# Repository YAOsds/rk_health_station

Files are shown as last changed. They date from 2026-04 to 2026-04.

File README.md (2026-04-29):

# RK Health Station

本工程是 `esp_health_watch` 的 RK3588 + ESP32 Qt 主站重构版本。

- rk_app/: RK3588 Qt/C++ 主站工程
- esp_fw/: ESP32 固件工程
- protocol/: 对外与本地 IPC 协议文档
- deploy/: systemd 与 bundle 部署脚本
- cmake/toolchains/: RK3588 交叉编译工具链文件

当前项目的主部署方式已经统一为：

- 宿主机 `Ubuntu 22.04` 上交叉编译
- 目标架构 `ARM64 / aarch64`
- 生成可直接传输到 RK3588 的 `rk3588_bundle/`
- 通过 `scp` / `rsync` / `ssh` 将 bundle 传到板端
- 在板端进入 bundle 目录后先编辑 `config/runtime_config.json`，或运行 `./scripts/config.sh`
- 然后使用 `./scripts/start.sh` 或 `./scripts/start_all.sh`

当前仓库默认对接的交叉 SDK 路径为：

- `/home/elf/aarch64-buildroot-linux-gnu_sdk-buildroot`

一键交叉编译并打包：

```bash
bash rk_health_station/deploy/scripts/build_rk3588_bundle.sh
```

只编译 `rk_app`：

```bash
# 当前 Ubuntu 主机本地编译
bash rk_health_station/deploy/scripts/build_rk_app.sh host

# RK3588 交叉编译
bash rk_health_station/deploy/scripts/build_rk_app.sh rk3588
```

默认输出目录：

- `rk_health_station/out/rk3588_bundle`

交叉编译完成后，必须再用 `file` 校验产物架构，例如：

```bash
file rk_health_station/out/rk3588_bundle/bin/healthd
file rk_health_station/out/rk3588_bundle/bin/health-ui
```

期望输出包含 `ARM aarch64`。

详细步骤见：

- `rk_health_station/docs/deployment/rk3588-backend-usage-guide.md`
- `rk_health_station/docs/deployment/rk3588-install.md`
- `rk_health_station/docs/architecture/camera-video-readme.md`

## RK3588 RGA 分析链路环境检查

RK3588 bundle 构建默认启用分析链路的 RGA 转换：

```text
camera/test input NV12 -> health-videod RGA -> RGB 640x640 -> shared memory -> health-falld
```

这个路径只影响跌倒检测所需的分析帧。UI 预览 JPEG 仍走 GStreamer 预览分支，预览编码使用 `mppjpegenc`。

板端运行前可以用下面命令确认环境是否具备 RGA 条件：

```bash
# 1. 确认 RGA 设备节点存在
ls -l /dev/rga

# 2. 确认当前用户具备访问权限；通常需要在 video 组
id

# 3. 确认系统可找到 librga
pkg-config --modversion librga
ldconfig -p | grep -E 'librga\.so'

# 4. 确认 health-videod 产物确实链接到 librga
ldd /home/elf/rk3588_bundle/bin/health-videod | grep rga
```

期望现象：

- `/dev/rga` 存在，且当前用户在 `video` 组或具备等效权限。
- `pkg-config --modversion librga` 能输出版本号。
- `ldd .../health-videod` 能看到 `librga.so`。

启动后可以继续确认当前分析后端：

```bash
cd /home/elf/rk3588_bundle
./scripts/start_all.sh

# 日志中应能看到 analysis_backend=rga
grep 'preview_started' logs/health-videod.log | tail -5

# 当前 GStreamer 分析分支应输出 NV12 到 fdsink，而不是 RGB videoconvert/videoscale
ps -ef | grep '[g]st-launch'
```

RGA 模式下的典型 GStreamer 分析分支形态为：

```text
... videorate drop-only=true ! video/x-raw,format=NV12,width=640,height=480,framerate=15/1 ! fdsink fd=1 sync=false
```

如果看到下面形态，则说明当前使用的是 CPU/GStreamer RGB 转换路径：

```text
... videoconvert ! videoscale ! video/x-raw,format=RGB,width=640,height=640,framerate=15/1 ! fdsink fd=1 sync=false
```

运行时可以用环境变量强制选择分析转换后端：

```bash
# 强制使用 RGA。仅建议在 RK3588 且已确认 /dev/rga 与 librga 可用时设置。
export RK_VIDEO_ANALYSIS_CONVERT_BACKEND=rga

# 强制回退到 GStreamer CPU 转换，便于 A/B 对比或排查 RGA 环境问题。
export RK_VIDEO_ANALYSIS_CONVERT_BACKEND=gstreamer_cpu
```

注意：如果在不具备 RGA 条件的环境中强制设置 `RK_VIDEO_ANALYSIS_CONVERT_BACKEND=rga`，分析分支可能会切到 NV12 输出，但 `health-videod` 无法完成 NV12 到 RGB 的 RGA 转换，导致跌倒检测收不到有效分析帧。遇到这种情况请取消该环境变量，或显式设置为 `gstreamer_cpu` 后重启 bundle。

## DMA / DMABUF 分析链路运行开关

当前仓库已经支持一条板端实测通过的 DMA 分析链路：

```text
GstBuffer / raw frame
-> health-videod 分析支路输入
-> RGA import 输入 fd 或映射后的 bytes
-> RGA 输出 RGB 到 DMA heap fd
-> fd descriptor 发给 health-falld
```

这条路径不是默认打开的，需要在 `config/runtime_config.json` 中显式打开；环境变量只建议作为临时 override。

### 推荐开关组合

在 RK3588 板端推荐直接把下面这些值写进 `config/runtime_config.json`：

```json
{
  "system": {
    "runtime_mode": "system"
  },
  "video": {
    "pipeline_backend": "inproc_gst",
    "analysis_convert_backend": "rga"
  },
  "analysis": {
    "transport": "dmabuf",
    "rga_output_dmabuf": true,
    "gst_dmabuf_input": true,
    "dma_heap": "/dev/dma_heap/system-uncached-dma32"
  },
  "fall_detection": {
    "rknn_input_dmabuf": true
  }
}
```

含义：

- `video.pipeline_backend = inproc_gst`
  - 启用进程内 GStreamer `appsink` 分析分支
  - 不再依赖外部 `gst-launch-1.0 + fdsink`
- `video.analysis_convert_backend = rga`
  - 分析分支使用 RGA 做缩放和颜色转换
- `analysis.transport = dmabuf`
  - `health-videod -> health-falld` 使用 fd descriptor transport
- `analysis.rga_output_dmabuf = true`
  - RGA 直接把 RGB 输出写到 DMA heap fd
- `analysis.gst_dmabuf_input = true`
  - 只启用 `appsink` 输入侧的 DMABUF 探测与日志
  - 如果当前协商出来的 `GstBuffer` 本身就是 `memory:DMABuf`，则优先走输入 fd 路径
  - 这个开关本身不再强制改变摄像头主链格式，也不再默认强制 `v4l2src io-mode=dmabuf`
- `fall_detection.rknn_input_dmabuf = true`
  - `health-falld` 优先走 RKNN 输入侧 DMABUF 路径
- `analysis.dma_heap = /dev/dma_heap/system-uncached-dma32`
  - 当前推荐的 DMA heap
  - 如果不设置，代码也会默认回到这个 heap

### 仍属实验/排查用途的开关

```bash
RK_VIDEO_GST_FORCE_DMABUF_IO=1 ./scripts/start.sh --backend-only
```

含义：

- 强制 `v4l2src io-mode=dmabuf`
- 同时允许 in-process GStreamer 切到实验性的 `UYVY` DMABUF 协商路径
- 当前更适合用作 A/B 对比、排障和板端能力确认
- 只有当板端驱动与插件协商稳定时，才建议写进长期配置

### 默认行为和回退

如果不设置这些开关，默认还是原来的稳定路径：

```text
外部 gst-launch -> raw frame bytes -> RGA/CPU -> shared memory 或 DMABUF descriptor
```

如果只打开一部分开关，行为是分层回退的：

- `video.pipeline_backend` 不是 `inproc_gst`
  - 不会启用进程内 `appsink`
- `analysis.rga_output_dmabuf` 没有打开
  - RGA 输出仍可能回到 `QByteArray` 再发布
- `analysis.gst_dmabuf_input = true` 但板端没有命中 DMABUF
  - 会自动回退到原始 bytes 输入路径
  - 不应丢帧
- `video.pipeline_backend = inproc_gst` 且 `input_mode=test_file`
  - 会自动回退到现有外部 `gst-launch` 文件播放路径
  - 不会再因为 in-process 后端未实现 `filesrc/decodebin` 而导致 `start_test_input` 失败

### 当前板端验证结论

当前这块 RK3588 板子截至 2026-04-29 的最新实测结论是：

- 默认 JSON 配置下，分析链路仍走稳定的 `gstreamer_cpu + shared_memory` 逻辑
- 当下面这组 JSON 配置一起打开时，板端已经实测命中一条完整的 0 拷贝优先路径：

```json
{
  "video": {
    "pipeline_backend": "inproc_gst",
    "analysis_convert_backend": "rga"
  },
  "analysis": {
    "transport": "dmabuf",
    "rga_output_dmabuf": true,
    "gst_dmabuf_input": true,
    "gst_force_dmabuf_io": true
  },
  "fall_detection": {
    "rknn_input_dmabuf": true
  }
}
```

- 对应日志会看到：

```text
video_runtime event=gst_dmabuf_input available payload_bytes=614400 stride=1280 format=UYVY
video_runtime camera=front_cam event=preview_started mode=camera backend=inproc_gst analysis=1 analysis_backend=rga
```

- `health-videod` marker 会看到：

```json
{"transport":"dmabuf","rga_input_dmabuf":true,"rga_output_dmabuf":true}
```

- `health-falld` marker 会看到：

```json
{"input_dmabuf_path":true,"io_mem_path":true,"output_prealloc_path":true}
```

- 也就是说，这块板子的当前高性能路径已经验证为：

```text
GStreamer DMABUF input -> RGA DMABUF output -> RKNN DMABUF input
```

- 这条链路仍依赖板端驱动、插件版本和摄像头协商结果；如果未来更换内核、插件或摄像头格式，仍建议重新做一次板端 smoke

### 板端启动示例

```bash
cd /home/elf/rk3588_bundle

./scripts/config.sh
./scripts/start.sh --backend-only
printf '%s\n' '{"action":"start_preview","request_id":"dmabuf-readme","camera_id":"front_cam","payload":{}}' | \
  nc -q 1 -U /home/elf/rk3588_bundle/run/rk_video.sock
```

如需临时 A/B 覆盖某个开关，优先用单次命令覆盖，而不是长期修改 shell 环境。例如：

```bash
RK_VIDEO_ANALYSIS_TRANSPORT=dmabuf ./scripts/start.sh --backend-only
```

### 板端验证要点

确认 `camera` 预览模式下没有外部 `gst-launch-1.0`：

```bash
ps -ef | grep gst-launch | grep -v grep
```

期望为空。

确认 `test_file` 模式会自动切回外部 pipeline：

```bash
ps -ef | grep '[g]st-launch'
```

期望能看到 `filesrc location=... ! decodebin ...` 的文件播放命令。

确认 `health-videod` 的 DMABUF 输入探测结果：

```bash
grep -E 'preview_started|gst_dmabuf_input' /home/elf/rk3588_bundle/logs/health-videod.log
```

默认 JSON 配置下，期望看到类似：

```text
video_runtime camera=front_cam event=preview_started mode=camera analysis=1 analysis_backend=gstreamer_cpu
```

0 拷贝 JSON 配置打开后，期望看到：

```text
video_runtime event=gst_dmabuf_input available payload_bytes=614400 stride=1280 format=UYVY
video_runtime camera=front_cam event=preview_started mode=camera backend=inproc_gst analysis=1 analysis_backend=rga
```

确认分析 descriptor 走 DMABUF：

```bash
grep 'analysis_descriptor_published' /tmp/rk_video_dmabuf_input.jsonl | head
```

0 拷贝 JSON 配置打开后，期望字段至少包含：

```json
{"transport":"dmabuf","rga_input_dmabuf":true,"rga_output_dmabuf":true}
```

同时 `health-falld` 侧应看到：

```json
{"input_dmabuf_path":true,"io_mem_path":true,"output_prealloc_path":true}
```

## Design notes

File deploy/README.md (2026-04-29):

# Deployment Assets

This directory contains deployment assets for the RK3588 station build.

Contents:
- `bundle/`: direct-run bundle scripts copied into `rk3588_bundle/`
- `config/runtime_config.json`: bundle 默认运行时配置
- `bundle/config.sh`: 独立配置 UI 启动入口
- `scripts/build_rk3588_bundle.sh`: one-click host-side cross-build and bundle pack script
- `scripts/install.sh`: optional systemd install flow
- `scripts/start.sh`: optional systemd start flow
- `scripts/stop.sh`: optional systemd stop flow
- `scripts/collect_logs.sh`: collect recent logs and runtime state
- `systemd/healthd.service`: backend daemon service
- `systemd/health-ui.service`: UI service

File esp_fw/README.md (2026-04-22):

# RK Health Station ESP32 Firmware

Standalone ESP-IDF firmware for the ESP32-S3 side of `rk_health_station`.

## What it does

- boots as a self-contained ESP-IDF project under `esp_fw/`
- exposes an AP provisioning portal when runtime config is missing
- connects to Wi-Fi and the RK3588 `healthd` TCP endpoint
- authenticates with `auth_hello -> auth_challenge -> auth_proof -> auth_result`
- samples MAX30102 and MPU6050 on the real hardware path by default
- computes `heart_rate`, `spo2`, `acceleration`, and `finger_detected`
- assembles rolling MPU6050 windows and emits a three-class IMU fall state
- uploads telemetry frames to the RK3588 backend
- drives dual LEDs to show boot / provisioning / Wi-Fi / pending approval / streaming / fault states

## Build

```bash
cd esp_fw
. ~/esp/esp-idf/export.sh
idf.py set-target esp32s3
idf.py build
```

## IMU fall classifier

```bash
bash tools/run_imu_model_pipeline.sh
cd esp_fw
. ~/esp/esp-idf/export.sh
idf.py build
```

This syncs the prebuilt model artifact from `/home/elf/workspace/imu_fall_detect/artifacts`
into `models/imu_fall_waist_3class.espdl` before rebuilding the firmware.

Real IMU fall-model inference requires:
1. Generate artifacts in `/home/elf/workspace/imu_fall_detect/imu_fall_model`
2. Sync artifacts into `esp_fw/models/` with `bash tools/run_imu_model_pipeline.sh`
3. Build firmware with PSRAM enabled
4. Flash and verify `FALL_CLS: esp-dl model loaded successfully`

## Flash

```bash
cd esp_fw
. ~/esp/esp-idf/export.sh
idf.py -p /dev/ttyACM0 erase_flash # clear flash
idf.py -p /dev/ttyACM0 flash
```

## Monitor

```bash
bash tools/serial_capture.sh /dev/ttyACM0 /tmp/esp_fw-session.log
```

You can also flash and open the serial monitor in one step:

```bash
cd esp_fw
. ~/esp/esp-idf/export.sh
idf.py -p /dev/ttyACM0 flash monitor
```

Exit the monitor with `Ctrl + ]`.

## Debugging on board

Recommended bring-up and debug flow:

1. Enter the firmware directory and load ESP-IDF:

```bash
cd esp_fw
. ~/esp/esp-idf/export.sh
```

2. Check the board serial port:

```bash
ls /dev/ttyACM* /dev/ttyUSB* 2>/dev/null
```

Use the actual serial device shown above in later commands. Many boards appear as
`/dev/ttyACM0`, while CH340-based boards often appear as `/dev/ttyUSB0`.

3. Rebuild and flash:

```bash
idf.py build
idf.py -p /dev/ttyUSB0 flash monitor
```

4. Watch the serial log for these key checkpoints:

- model loaded:
  - `FALL_CLS: model_size=...`
  - `FALL_CLS: model_addr=0x........ aligned16=1`
  - `FALL_CLS: largest_internal_kb=... largest_psram_kb=...`
  - `FALL_CLS: esp-dl model loaded successfully`
- IMU inference is active:
  - `imu_fall class=<0|1|2> probs=[...]`
- networking is active:
  - `wifi connected ...`
  - `auth ...`
  - `telemetry sent ...`

5. Interpret the IMU classes as:

- `class=0`: `non_fall`
- `class=1`: `pre_impact`
- `class=2`: `fall`

6. Recommended motion test sequence:

- keep the board still or walk normally and confirm it is mostly `class=0`
- do a fast imbalance / crouch / pre-drop motion and check whether `class=1` appears
- simulate a fall or rapid lay-down and check whether `class=2` probability rises clearly

7. If you only want to validate the on-device IMU model, you do not need the full RK3588 link first. The minimum success criteria are:

- `FALL_CLS: esp-dl model loaded successfully`
- repeated `imu_fall class=... probs=[...]` lines after the rolling IMU window fills

Common failure hints:

- no `esp-dl model loaded successfully`:
  - the embedded `.espdl` artifact is missing, empty, misaligned, or PSRAM-backed load failed
- no `imu_fall class=...` lines:
  - the MPU6050 path is not producing data yet, or the rolling 256-sample window is not full
- repeated Wi-Fi / auth retry logs:
  - the local model may still be running, but the RK3588 uplink path is not ready

## AP provisioning

If the device has no valid config, it starts AP provisioning automatically:

- SSID format: `RKHealth-XXXX`
- password: `rkhealth01`
- portal URL: `http://192.168.4.1/`

Required fields in the provisioning form:

- Wi-Fi SSID / password
- RK3588 `server_ip`
- RK3588 `server_port`
- `device_id`
- `device_name`
- `device_secret`

The portal scans nearby APs automatically and refreshes the SSID dropdown every 3 seconds; users only select a discovered SSID and enter the password.

After saving the form, the device stores config in NVS and reboots into STA mode.

While the device is waiting in provisioning mode, serial logs emit a heartbeat every 3 seconds with the current AP client count and latest Wi-Fi scan summary.

## Local verification

```bash
bash tools/run_host_checks.sh
```

This runs the external IMU model tests from `/home/elf/workspace/imu_fall_detect/imu_fall_model/tests`,
the provisioning host-side checks, and then a full `idf.py build`.

## Helpful scripts

- `tools/run_host_checks.sh`: README keyword checks + full build
- `tools/serial_capture.sh`: wraps `idf.py monitor` and saves serial logs
- `tools/push_bundle_to_board.sh`: copies firmware artifacts and docs to the RK3588 side

## More docs

- `docs/esp-firmware-architecture.md`
- `docs/esp-imu-fall-validation-report.md`
- `docs/esp-provisioning-guide.md`

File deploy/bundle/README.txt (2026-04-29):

RK3588 bundle runtime

Contents:
- bin/healthd
- bin/health-ui
- bin/health-videod
- bin/health-falld
- bin/health-config-ui
- config/runtime_config.json
- scripts/config.sh
- scripts/start.sh
- scripts/start_all.sh
- scripts/stop.sh
- scripts/stop_all.sh
- scripts/status.sh

Board-side quick start:
1. copy the whole rk3588_bundle directory to the board
2. enter the bundle directory
3. edit `config/runtime_config.json`, or run `./scripts/config.sh`
4. run `./scripts/start.sh`
5. check `./scripts/status.sh`
6. stop with `./scripts/stop.sh`

Board-side one-click start/stop:
- `./scripts/start_all.sh`
- `./scripts/stop_all.sh`
- `start_all.sh` will try to infer `DISPLAY` from `~/.Xauthority`, set
  `XAUTHORITY=$HOME/.Xauthority`, and then verify all three processes are alive

Optional backend-only start:
- `./scripts/start.sh --backend-only`

Advanced overrides:
- environment variables still win over JSON for temporary experiments
- example: `RK_VIDEO_ANALYSIS_TRANSPORT=dmabuf ./scripts/start.sh --backend-only`

If the UI cannot open, check:
- DISPLAY / WAYLAND_DISPLAY / QT_QPA_PLATFORM
- logs/health-ui.log
- board-side Qt runtime compatibility
- on Ubuntu boards using system Qt runtime, install:
  `libqt5multimedia5 libqt5multimedia5-plugins libqt5multimediagsttools5 libqt5multimediawidgets5`

Video monitor notes:
- `health-videod` is the only process that opens `/dev/video11`
- default media directory on board: `/home/elf/videosurv/`
- current preview transport is local `TCP + MJPEG`
- current preview URL shape is `tcp://127.0.0.1:5602?transport=tcp_mjpeg&boundary=rkpreview`
- `health-ui` consumes preview frames through `QTcpSocket`; it does not open `/dev/video11`

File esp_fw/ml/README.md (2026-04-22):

Offline IMU model training no longer lives in this firmware tree.
Use /home/elf/workspace/imu_fall_detect/imu_fall_model instead.

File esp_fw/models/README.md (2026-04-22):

# Model Artifacts

Generated model artifacts are produced outside this firmware tree.

Canonical offline workspace:
- `/home/elf/workspace/imu_fall_detect/imu_fall_model`

The firmware build currently requires this artifact in `esp_fw/models/`:
- `imu_fall_waist_3class.espdl`

Optional sidecar metadata may also be synced when present:
- `imu_fall_waist_3class.info`
- `imu_fall_waist_3class.json`

Refresh flow:
1. Generate artifacts in `/home/elf/workspace/imu_fall_detect/artifacts`
2. Run `bash esp_fw/tools/run_imu_model_pipeline.sh`
3. Rebuild firmware with `idf.py build`

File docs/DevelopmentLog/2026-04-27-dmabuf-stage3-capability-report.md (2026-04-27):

# 2026-04-27 DMABUF Stage 3 Capability Report

## Board

- Host: `elf2-desktop`
- Kernel: `Linux 5.10.209 aarch64`
- User groups include `video`, so `/dev/rga`, `/dev/video*`, and public dma-heap nodes are accessible without sudo.

## Device Nodes

Available:

- `/dev/rga` owned by `root:video`, mode `crw-rw----`
- `/dev/video11` active camera path, driver `rkisp_v6`, card `rkisp_mainpath`
- `/dev/dma_heap/system-dma32`, `/dev/dma_heap/system-uncached`, `/dev/dma_heap/system-uncached-dma32` open read/write as user `elf`
- `/dev/dma_heap/cma`, `/dev/dma_heap/cma-uncached`, `/dev/dma_heap/system` are root-only and not usable without permission changes
- `/dev/dri/renderD128` and `/dev/dri/renderD129` exist but user `elf` is not in `render`; not needed for the first RGA/RKNN probe

## Camera / V4L2

`/dev/video11` reports:

- Driver: `rkisp_v6`
- Device caps: `Video Capture Multiplanar`, `Streaming`, `Extended Pix Format`
- Current format: `640x480`, `NM12`, two planes
- Enumerated formats include `NV12`, `NV21`, `NM12`, `NM21`, `NV16`, `NV61`, and `UYVY`

## GStreamer

`v4l2src` supports the required IO modes:

- `io-mode=dmabuf`
- `io-mode=dmabuf-import`
- `io-mode=mmap`

Smoke tests after stopping the running bundle:

| Pipeline | Result |
| --- | --- |
| `v4l2src io-mode=dmabuf num-buffers=5 ! ... ! fakesink` | exit `0` |
| `v4l2src io-mode=mmap num-buffers=5 ! ... ! fakesink` | exit `0` |
| `v4l2src io-mode=dmabuf-import num-buffers=5 ! ... ! fakesink` | exit `1`, expected without downstream pool |

Implication: capture-side DMABUF export is available. The current `gst-launch + fdsink fd=1` topology still cannot transfer DMABUF fds through stdout; production fd passing will need in-process GStreamer or a helper process that uses Unix-domain fd passing.

## RGA

Headers in the cross sysroot expose fd-backed APIs:

- `importbuffer_fd(...)`
- `releasebuffer_handle(...)`
- `wrapbuffer_fd(...)`
- `wrapbuffer_handle(...)`

Current production code still uses `wrapbuffer_virtualaddr(...)` in `RgaFrameConverter`, so the next probe should exercise `dma_heap -> importbuffer_fd/wrapbuffer_fd -> imcheck/imcopy/improcess` on the board.

## RKNN

Board runtime libraries export required fd/IO-memory symbols:

- `rknn_create_mem_from_fd`
- `rknn_set_io_mem`
- `rknn_mem_sync`

Checked in:

- `/usr/lib/librknnrt.so`
- `/usr/lib64/librknnrt.so`
- `/home/elf/rk3588_bundle/lib/app/librknnrt.so`

Implication: RKNN fd import is technically available, but prior full IO-memory timing was neutral/regressive, so RKNN fd import must be measured in a sidecar probe before it becomes production default.

## Recommendation

Proceed with a sidecar RGA fd probe first:

1. Allocate RGB buffers from `/dev/dma_heap/system-uncached-dma32` or `/dev/dma_heap/system-dma32`.
2. Import/wrap them through RGA fd APIs.
3. Run a simple `imfill` / `imcopy` / resize operation and verify output bytes through `mmap`.
4. Only after that succeeds, add RKNN fd-import timing against the pose model.

Do not modify the production shared-memory frame transport yet.

## Sidecar RGA DMABUF Probe Result

Added a sidecar-only probe source and build script:

- `deploy/probes/rga_dmabuf_probe.cpp`
- `deploy/scripts/build_rga_dmabuf_probe.sh`

The probe allocates two RGB888 DMA buffers, imports them with RGA fd APIs, runs `imcopy`, and verifies the copied bytes through `mmap`.

Board results:

| Heap | Result | Interpretation |
| --- | --- | --- |
| `/dev/dma_heap/system-uncached-dma32` | `rga_dmabuf_probe_ok`, exit `0` | Recommended first production/probe heap |
| `/dev/dma_heap/system-uncached` | `rga_dmabuf_probe_ok`, exit `0` | Also viable |
| `/dev/dma_heap/system-dma32` | verify mismatch at byte `0`, exit `7` | Cache coherency/sync issue for CPU-written cached memory in this simple probe |

Conclusion: RGA fd-backed DMABUF operation is verified on the board. The first real probe should use an uncached heap unless explicit cache synchronization is added for cached heaps.

## Sidecar RKNN DMABUF Input Probe Result

Added a sidecar-only RKNN input probe:

- `deploy/probes/rknn_dmabuf_input_probe.cpp`

The probe loads the pose RKNN model, allocates a DMA buffer for the RGB input tensor, imports it with `rknn_create_mem_from_fd`, binds it with `rknn_set_io_mem`, runs 30 inferences on a constant input, and uses normal `rknn_outputs_get` for outputs.

Board results while the production bundle was stopped:

| Heap | Result | `avg_run_ms` | `avg_outputs_get_ms` | Interpretation |
| --- | --- | ---: | ---: | --- |
| `/dev/dma_heap/system-uncached-dma32` | exit `0` | `25.129` | `1.592` | Works, but slower than production timing |
| `/dev/dma_heap/system-uncached` | exit `0` | `23.667` | `1.546` | Works, closest candidate among tested heaps |
| `/dev/dma_heap/system-dma32` | exit `0` | `24.157` | `1.545` | Works with explicit `rknn_mem_sync`, but RGA copy probe showed CPU/RGA coherency risk |

Production Stage 1/2 timing for comparison was around `rknn_run_ms avg 21.54` and `outputs_get_ms avg 1.0` in the integrated service. Therefore RKNN input DMABUF import is functionally available, but it should not be assumed faster than the current input path. The value of DMABUF remains strongest for removing cross-process payload copies and improving 25 FPS stability, not for making RKNN compute itself faster.

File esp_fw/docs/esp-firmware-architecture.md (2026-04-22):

# ESP Firmware Architecture

## Runtime overview

The ESP firmware is split into small components and a thin `main/` orchestration layer.

### Boot path

1. `app_main.c` enters `app_controller_run()`.
2. `app_controller` initializes board config, diagnostics, NVS, and LED status.
3. If config is missing, the firmware starts the AP provisioning portal and waits for a reboot after save.
4. If config is valid, the firmware starts three FreeRTOS tasks:
   - `sensor_task`
   - `link_task`
   - `telemetry_task`

## Component responsibilities

### Core platform

- `board_config`: hardware pins and timing defaults
- `system_diag`: low-overhead runtime snapshot for stage / retry / signal quality tracking
- `config_store`: NVS-backed persisted runtime config
- `provisioning_portal`: SoftAP + HTTP form entry for Wi-Fi and RK3588 credentials

### Connectivity

- `wifi_manager`: STA connection lifecycle
- `net_client`: TCP framing transport (`4-byte big-endian length + JSON`)
- `auth_client`: auth handshake codec and proof generation
- `telemetry`: telemetry frame construction and authenticated upload wrapper

### Sensors and algorithms

- `max30102`: PPG sensor driver using ESP-IDF 6 I2C master API
- `mpu6050`: accelerometer / gyro driver using ESP-IDF 6 I2C master API
- `signal_filter`: window analysis, finger detection, signal confidence, motion estimate
- `heart_rate_algo`: converts analyzed signal quality into vital-sign outputs
- `imu_window_buffer`: keeps a rolling `256 x 6` IMU tensor with stride-based emission
- `fall_classifier`: wraps the on-device IMU fall classifier interface, logs model-size/alignment/heap diagnostics, and loads the aligned `.espdl` artifact from flash rodata
- `imu_event_state`: smooths consecutive fall windows before telemetry emission

### UI feedback

- `led_status`: maps runtime state to dual-LED patterns and runs the blink task

## Task model

### `sensor_task`

- initializes MAX30102 and MPU6050
- samples real sensor data continuously
- keeps a rolling PPG window and motion history
- keeps a rolling IMU window for the fall classifier
- computes `heart_rate`, `spo2`, `acceleration`, `finger_detected`
- computes `imu_fall_valid`, `imu_fall_class`, and the three class probabilities
- publishes the latest computed vitals into shared runtime state

### `link_task`

- connects to Wi-Fi
- initializes the telemetry uploader once Wi-Fi is ready
- tracks link loss and restarts the connection loop when Wi-Fi drops

### `telemetry_task`

- waits for both valid vitals and a ready link
- builds `telemetry_batch` JSON frames
- lets the uploader handle auth + send
- updates LED state and diagnostics based on `authenticated / pending / rejected / failed`

## Data flow

1. MAX30102 raw PPG + MPU6050 motion samples enter `sensor_task`.
2. `signal_filter` derives signal quality and motion level.
3. `heart_rate_algo` converts quality metrics into heart rate / SpO2 outputs.
4. `imu_window_buffer` and `fall_classifier` derive a three-class IMU fall state.
5. `telemetry_task` packages those outputs with device metadata.
6. `telemetry_uploader` authenticates and pushes the data to RK3588 `healthd`.

## Debugging signals

- serial logs annotate boot, Wi-Fi state, sensor init, telemetry send, and auth outcomes
- serial logs print fall-classifier memory diagnostics before `esp-dl` model load
- serial logs also print `imu_fall class=<n> probs=[p0 p1 p2]` after each emitted IMU window
- `system_diag` keeps retry counters plus latest signal confidence / motion level
- `led_status` gives physical visibility into the current lifecycle state

## Model artifact ownership

- Offline training and export live in `/home/elf/workspace/imu_fall_detect/imu_fall_model`
- Firmware consumes the generated `.espdl` artifact from `esp_fw/models/`
- `tools/run_imu_model_pipeline.sh` now checks or syncs prebuilt artifacts only; it no longer trains in the firmware tree
- `components/fall_classifier/CMakeLists.txt` uses aligned binary embedding so the flash-rodata model address stays 16-byte aligned for `esp-dl`
- PSRAM is enabled in `sdkconfig.defaults` so `esp-dl` can allocate its runtime buffers without the earlier crash path

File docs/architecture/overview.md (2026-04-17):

# Architecture Overview

## Product Shape

- one RK3588 main station runs the whole backend and UI locally
- multiple ESP32 wearable devices connect over the same external WiFi router
- RK3588 software is split into two Qt/C++ processes:
  - `healthd`: backend daemon
  - `health-ui`: frontend application

## Data Paths

### Device to Backend

- ESP32 -> WiFi -> TCP -> `healthd`
- protocol is length-prefixed compact JSON
- devices authenticate through `auth_hello -> auth_challenge -> auth_proof -> auth_result`
- only authenticated devices can push telemetry into the main backend path

### Backend to UI

- `health-ui` never talks to devices directly
- `health-ui` only uses local IPC exposed by `healthd`
- local IPC transport is `QLocalServer` / `QLocalSocket` with newline-delimited JSON

## Backend Responsibilities

`healthd` is responsible for:
- device admission and approval workflow
- device secret verification and runtime session auth
- telemetry storage into SQLite
- minute aggregation generation
- alert evaluation
- local IPC responses for UI pages

## UI Responsibilities

`health-ui` is responsible for:
- dashboard display
- device list and detail navigation
- pending-device approval operations
- device settings operations
- alerts snapshot display
- minute history query display

## Persistence

SQLite stores:
- device metadata
- pending device requests
- audit log
- raw telemetry samples
- minute aggregation data

## Security Model

- device credentials are provisioned per ESP32
- unknown devices enter pending approval instead of becoming active automatically
- disabled or rejected devices are blocked from authenticated telemetry
- UI management operations flow through backend policy checks

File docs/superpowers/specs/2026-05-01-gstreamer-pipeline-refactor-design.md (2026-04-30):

# GStreamer Pipeline Refactor Design

Date: 2026-05-01
Status: Approved for planning

## 1. Goal

Refactor `health-videod`'s GStreamer pipeline code so preview lifecycle, command construction, analysis-frame publishing, and low-level transport helpers no longer live in the same large class.

The design goal is maintainability and safer iteration, not behavior change. Preview, recording, snapshot, analysis transport, and runtime configuration semantics must remain compatible with the current implementation.

## 2. User-Approved Direction

The approved direction is:

- accept the current class structure as the main design problem
- split responsibilities by change reason, not just by file length
- improve testability by removing the need for `friend` access and private-state setup in tests
- apply the same refactoring principle to `InprocessGstreamerPipeline`
- avoid over-design; only introduce factory indirection where there is real runtime strategy selection

## 3. Current Problem

`GstreamerVideoPipelineBackend` currently mixes four independent concerns:

1. command construction
2. process lifecycle and stop/start policy
3. analysis-frame conversion and publishing
4. low-level IO helpers such as MJPEG multipart parsing, preview TCP frame reads, and DMA-BUF allocation

These concerns change for different reasons:

- command strings change when pipeline topology changes
- lifecycle logic changes when process supervision rules change
- frame publishing changes when analysis transport or conversion rules change
- IO helpers change when DMA-BUF or preview transport details change

Because they are coupled in one type, a change in one area requires re-reading unrelated code paths before it is safe to modify anything.

## 4. Evidence in the Current Code

The current structure already shows boundary leakage:

- the backend header exposes command builders, transport parsing helpers, lifecycle methods, and frame-processing methods in one class
- `ActivePipeline` stores process handles, in-process pipeline handles, analysis-format metadata, frame counters, stdout buffers, shared-memory writers, and runtime log stats in one struct
- tests depend on `friend class GstreamerVideoPipelineBackendTest` and directly mutate private backend state to exercise DMA analysis paths

This is not only a readability issue. It is a boundary-design issue that makes testing and future changes more fragile.

## 5. Design Principles

The refactor must follow these rules:

1. Preserve current external behavior.
2. Keep the default external `gst-launch` path and the optional in-process GStreamer path working.
3. Separate orchestration from implementation details.
4. Prefer composition over inheritance.
5. Introduce interfaces only at boundaries that truly need interchangeable implementations.
6. Keep internal helper types concrete unless there is a demonstrated need for runtime selection or mocking.

## 6. Recommended Architecture

### 6.1 Backend Role

`GstreamerVideoPipelineBackend` becomes a coordinator. Its job is limited to:

- receiving public backend API calls
- selecting preview execution mode
- creating or acquiring a per-camera session object
- wiring callbacks between lifecycle and analysis publishing
- forwarding runtime errors to `VideoPipelineObserver`

It should no longer contain command-string assembly, direct frame conversion logic, or transport helper implementations.

### 6.2 Per-Camera Session

Promote the current `ActivePipeline` state into a focused session object, for example `PipelineSession`.

Its responsibility is to hold mutable per-camera state:

- camera id and preview URL
- preview/recording running state
- process or in-process runner handles
- analysis input/output geometry and format metadata
- next frame id
- shared-memory ring writer
- rolling log statistics

This keeps state ownership explicit and avoids spreading per-camera fields across multiple unrelated helpers.

### 6.3 Command Construction

Extract preview, recording, snapshot, and preview-stream-recording command generation into a concrete `GstCommandBuilder`.

Responsibilities:

- quote shell arguments
- map runtime config to launch binary selection
- build preview/recording/snapshot command strings
- build the external analysis tap fragment
- derive preview URL, port, and boundary helpers if they remain command-related

Non-responsibilities:

- starting processes
- reading sockets
- converting frames
- publishing descriptors

This class is a good extraction target because its behavior is already heavily covered by command-string tests.

### 6.4 External Process Lifecycle

Extract process supervision into `GstProcessRunner`.

Responsibilities:

- start `QProcess`
- perform startup probe timing
- connect stdout/stderr handling callbacks
- stop preview and recording processes with current SIGINT/kill fallback semantics
- surface exit failures through callbacks

This class owns lifecycle policy, not analysis logic.

### 6.5 Analysis Frame Publishing

Extract frame conversion and publication into `AnalysisFramePublisher`.

Responsibilities:

- accept raw byte frames or DMA input frames
- perform CPU or RGA conversion
- choose shared-memory or DMA-BUF descriptor publication
- update frame ids and timestamps
- write runtime log summaries and latency markers

This class should receive a session-like state object plus dependencies such as:

- `AnalysisFrameSource`
- `AnalysisFrameConverter`
- runtime analysis config

The important design point is that backend orchestration should not know how RGB payloads or DMA descriptors are produced.

### 6.6 IO and Transport Helpers

Low-level helpers should move out of the backend into focused utility classes or file-local helpers with narrow headers:

- `PreviewStreamReader`
  - parse preview URL
  - read one JPEG frame from TCP multipart MJPEG
- `MultipartJpegParser`
  - incremental multipart boundary parsing
- `DmaBufferAllocator`
  - allocate memfd or dma-heap buffers
  - mmap and write payloads when needed

These helpers do not need factories or broad interfaces in the first refactor step.

## 7. Factory and Interface Strategy

### 7.1 Where Factory Indirection Is Valuable

Factory indirection is justified at the pipeline execution boundary, because there is real runtime strategy selection today:

- external `gst-launch` preview path
- in-process GStreamer preview path

For that boundary, a small factory is useful. Example shape:

- `PipelineRunnerFactory`
- returns either `ExternalGstreamerRunner` or `InprocessGstreamerRunner`

The backend can then depend on a runner interface instead of directly constructing one concrete implementation path.

### 7.2 Where Factory Indirection Is Not the First Priority

Factory indirection is not the main value for:

- command builders
- preview stream readers
- DMA allocators
- multipart parsers

Those areas mainly need extraction and local clarity. Introducing interfaces there immediately would add ceremony without solving a concrete runtime-selection problem.

### 7.3 Recommendation

Do not make "introduce factories everywhere" the first step. The recommended order is:

1. split responsibilities into concrete components
2. stabilize data flow and tests around the new boundaries
3. add a factory only at the runner-selection boundary

This keeps the design simpler while still decoupling the only place that already has multiple execution strategies.

## 8. In-Process Pipeline Refactor

`InprocessGstreamerPipeline` should follow the same rule: keep it as a small lifecycle owner and move its major concerns into collaborators.

Recommended internal breakdown:

- `InprocessLaunchDescriptionBuilder`
  - builds the `gst_parse_launch()` string
- `GstBusMonitor`
  - polls the bus and maps EOS and error messages into runtime error callbacks
- `GstAppSinkFrameDispatcher`
  - handles `GstSample` extraction
  - chooses DMA input path or mapped byte fallback
  - emits queued callbacks onto the Qt thread

After this split, `InprocessGstreamerPipeline` should mainly own:

- `start()`
- `stop()`
- callback registration
- construction and teardown of GStreamer objects

This is enough abstraction for the current codebase. A larger plugin-style architecture is unnecessary at this stage.

## 9. Testing Strategy

The refactor should improve tests, not just move code around.

Target outcomes:

- command tests move to `GstCommandBuilder` without needing backend friendship
- analysis publication tests exercise `AnalysisFramePublisher` directly with fake converters and fake frame sources
- preview stream parsing tests target `PreviewStreamReader` and `MultipartJpegParser` directly
- backend tests focus on orchestration behavior:
  - backend selection
  - preview/recording lifecycle wiring
  - observer notifications
  - session cleanup

The direct mutation of backend private state in tests should disappear once `PipelineSession` and `AnalysisFramePublisher` have explicit seams.

## 10. Implementation Phases

### Phase 1: Safe Extraction

- extract `GstCommandBuilder`
- extract `PreviewStreamReader` and multipart parser helper
- extract DMA allocation helper
- keep backend behavior unchanged

### Phase 2: Session and Publisher Split

- introduce `PipelineSession`
- extract `AnalysisFramePublisher`
- move frame-conversion and descriptor publication logic out of backend

### Phase 3: Lifecycle Split

- extract `GstProcessRunner`
- move start/stop/supervision logic out of backend

### Phase 4: Runner Selection Abstraction

- add a narrow runner interface and factory for external vs in-process preview execution
- keep command builder and IO helpers concrete

### Phase 5: In-Process Internal Cleanup

- split `InprocessGstreamerPipeline` into launch-description builder, bus monitor, and appsink dispatcher collaborators

## 11. Risks and Controls

Main risks:

- subtle behavior changes in process shutdown and startup probe timing
- breaking analysis descriptor semantics during publisher extraction
- moving too many pieces at once and losing confidence in equivalence

Controls:

- refactor in phases with tests moved alongside each extraction
- preserve current public API and runtime config names
- avoid mixing behavioral changes with structural changes in the same patch
- keep the external `gst-launch` path as the baseline reference during refactor

## 12. Out of Scope

This design does not include:

- changing preview transport away from local MJPEG TCP
- redesigning `health-falld` analysis protocols
- changing camera ownership rules
- introducing a generic media graph framework
- replacing all concrete helpers with abstract interfaces

## 13. Final Recommendation

The proposed refactor is worth doing, but it should be executed in a narrower and more disciplined form than "add factories everywhere."

The highest-value sequence is:

1. extract command building
2. extract analysis frame publishing
3. introduce an explicit per-camera session object
4. then add a factory only for external vs in-process runner selection

That sequence addresses the real pain in the current codebase while avoiding unnecessary abstraction overhead.

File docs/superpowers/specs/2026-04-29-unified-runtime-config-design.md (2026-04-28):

# Unified Runtime Configuration Design

## Goal

Replace the RK3588 bundle's user-facing runtime environment variables and scattered hard-coded runtime paths with a single JSON configuration file plus a dedicated Qt configuration application, while preserving environment-variable overrides for development, testing, and board-side experiments.

## Scope

- Add one shared runtime configuration model used by `healthd`, `health-videod`, `health-falld`, `health-ui`, and a new `health-config-ui`.
- Move user-facing runtime settings out of per-module `qEnvironmentVariable(...)` reads and into a single JSON file.
- Cover all currently user-tuned runtime fields, including normal runtime settings, advanced performance knobs, and debug or probe output paths.
- Keep environment-variable override support for compatibility, but centralize it in one configuration layer.
- Add a dedicated standalone Qt application for editing, validating, and saving the JSON configuration file.
- Update bundle startup scripts and bundle packaging so the normal user path becomes "edit JSON or launch config UI, then run `start.sh`".

## Non-Goals

- Do not add hot-reload of runtime configuration while services are already running.
- Do not add automatic service restart orchestration after config changes in this first version.
- Do not expose every internal implementation constant as a user-facing setting; protocol literals, fixed internal timeouts, and compile-time feature flags remain code-owned.
- Do not merge configuration editing into the existing `health-ui`; configuration lives in a separate executable.

## Current Problems

The current project mixes three configuration mechanisms in ways that are hard for users to understand:

1. User-facing runtime behavior depends on many environment variables such as `RK_VIDEO_PIPELINE_BACKEND`, `RK_VIDEO_ANALYSIS_TRANSPORT`, `RK_VIDEO_RGA_OUTPUT_DMABUF`, `RK_FALL_RKNN_INPUT_DMABUF`, and multiple socket/model/debug paths.
2. Several runtime defaults are hard-coded inside service code, including camera id, video device path, storage directory, database path, socket names, and model paths.
3. Bundle startup scripts export a large set of values before launching services, which forces users to memorize shell commands instead of editing one discoverable configuration file.

This makes normal deployment unfriendly, makes configuration provenance unclear, and blocks a future user-facing editor because every service currently owns part of its own configuration loading logic.

## Recommended Architecture

Introduce a single shared `AppRuntimeConfig` model under `rk_app/src/shared/runtime_config/`. All runtime configuration loading, path expansion, validation, defaults, and environment-variable overrides happen there. Service code receives typed config objects and stops reading environment variables directly.

The bundle ships one runtime file at `config/runtime_config.json`. A new standalone executable, `health-config-ui`, edits that file offline and shows field-level validation errors. Existing services read the same file at startup. Environment variables remain supported, but only as a final override layer for advanced development and board-side experiments.

## Configuration Source Priority

Runtime values resolve in this order:

1. Explicit environment-variable override
2. `config/runtime_config.json`
3. Built-in default value

This preserves compatibility with existing debug and benchmarking workflows while making the JSON file the primary user-facing configuration source.

## Runtime File Location

- Source template in the repo: `deploy/config/runtime_config.json`
- Bundle runtime file on target: `rk3588_bundle/config/runtime_config.json`
- Optional explicit override path: `RK_APP_CONFIG_PATH=/path/to/runtime_config.json`

Bundle scripts should default to the bundled `config/runtime_config.json`. Users should not need to export individual runtime env vars for normal startup.

## JSON Structure

The configuration file should be organized by user-understandable functional areas instead of by daemon name. The top-level shape is:

```json
{
  "system": {},
  "paths": {},
  "ipc": {},
  "video": {},
  "analysis": {},
  "fall_detection": {},
  "debug": {}
}
```

Recommended representative structure:

```json
{
  "system": {
    "runtime_mode": "auto"
  },
  "paths": {
    "storage_dir": "/home/elf/videosurv/",
    "database_path": "./data/healthd.sqlite"
  },
  "ipc": {
    "health_socket": "./run/rk_health_station.sock",
    "video_socket": "./run/rk_video.sock",
    "analysis_socket": "./run/rk_video_analysis.sock",
    "fall_socket": "./run/rk_fall.sock"
  },
  "video": {
    "camera_id": "front_cam",
    "device_path": "/dev/video11",
    "pipeline_backend": "inproc_gst",
    "analysis_enabled": true,
    "analysis_convert_backend": "rga",
    "gst_launch_bin": "gst-launch-1.0"
  },
  "analysis": {
    "transport": "dmabuf",
    "dma_heap": "/dev/dma_heap/system-uncached-dma32",
    "rga_output_dmabuf": true,
    "gst_dmabuf_input": true,
    "gst_force_dmabuf_io": false
  },
  "fall_detection": {
    "enabled": true,
    "pose_model_path": "./assets/models/yolov8n-pose.rknn",
    "action_backend": "lstm_rknn",
    "lstm_model_path": "./assets/models/lstm_fall.rknn",
    "stgcn_model_path": "./assets/models/stgcn_fall.rknn",
    "rknn_input_dmabuf": true,
    "rknn_io_mem_mode": "default"
  },
  "debug": {
    "video_latency_marker_path": "",
    "fall_latency_marker_path": "",
    "fall_pose_timing_path": "",
    "fall_track_trace_path": "",
    "fall_action_debug": false,
    "fall_lstm_trace_path": ""
  }
}
```

## Field Coverage

The first version should cover all current user-tuned runtime knobs that are now spread across code and shell setup:

- Core runtime selection, bundle paths, and storage/database locations
- IPC socket paths and shared-memory naming overrides
- Camera identity and device path
- Video backend selection and analysis enablement
- GStreamer launch binary override for development
- Analysis transport choice and DMA heap path
- RGA, GstBuffer DMABUF, forced DMABUF I/O, and RKNN DMABUF/I/O-memory knobs
- Fall-detection models, action backend selection, tracker tuning, and sequence length
- Debug, marker, trace, and probe output paths

Pure code-owned constants such as protocol field names, fixed observer callbacks, and compile-time feature availability remain out of the JSON file.

## Shared Runtime Configuration Module

Create a new shared module at `rk_app/src/shared/runtime_config/` with these responsibilities:

- `app_runtime_config.h/.cpp`
  - Define the full typed configuration model.
- `app_runtime_config_loader.h/.cpp`
  - Load JSON, merge defaults, and apply environment-variable overrides.
- `app_runtime_config_validator.h/.cpp`
  - Validate enum values, numeric ranges, required paths, and user-facing consistency rules.
- `app_runtime_config_paths.h/.cpp`
  - Resolve relative paths against bundle root or config-file directory and normalize output paths.

The shared module should expose:

- Full application config: `AppRuntimeConfig`
- Service-specific views or mapped structs:
  - `HealthdRuntimeConfig`
  - `VideoRuntimeConfig`
  - `FallRuntimeConfig`
  - `UiRuntimeConfig`
- A validation result object that contains:
  - blocking errors
  - warnings
  - normalized effective values
  - per-field origin metadata such as `default`, `config`, or `environment`

## Service Integration Strategy

### `healthd`

Replace direct environment reads for database path and related runtime marker settings with values derived from shared configuration. `healthd` should receive typed config on startup and log the effective database path, socket path, and marker status with source information.

### `health-videod`

Centralize current runtime selection now spread across:

- `rk_app/src/health_videod/core/video_service.cpp`
- `rk_app/src/health_videod/pipeline/gstreamer_video_pipeline_backend.cpp`
- `rk_app/src/health_videod/pipeline/inprocess_gstreamer_pipeline.cpp`
- `rk_app/src/health_videod/analysis/gstreamer_analysis_output_backend.cpp`
- `rk_app/src/health_videod/analysis/rga_frame_converter.cpp`
- `rk_app/src/health_videod/ipc/video_gateway.cpp`

These files should stop reading environment variables directly and instead consume one injected `VideoRuntimeConfig`.

### `health-falld`

Keep the existing `FallRuntimeConfig` concept, but make it a mapped view from shared configuration instead of a local environment parser. This preserves current code shape while removing duplicate config-loading logic.

### `health-ui`

Limit `health-ui` to only the small runtime settings it actually needs, such as IPC connection targets. It should not become a configuration editor or own business-runtime defaults.

## Standalone Configuration Application

Add a new Qt executable:

- path: `rk_app/src/health_config_ui/`
- binary: `health-config-ui`

This application is a dedicated offline configuration editor and is not linked into the existing `health-ui` navigation.

### UI Requirements

- Open and edit the bundle JSON config without requiring `healthd`, `health-videod`, or `health-falld` to be running
- Show the current config file path prominently
- Track dirty state, validation state, and last save result
- Provide actions for:
  - reload
  - validate
  - save
  - restore defaults
- Organize fields into user-facing groups:
  - Basic
  - Paths
  - Video
  - Analysis
  - Fall Detection
  - Debug and Diagnostics
- Use user-friendly labels instead of environment-variable names
- Show field help text, default value hints, and warning badges for experimental items such as forced DMABUF I/O

### Validation Behavior

- Blocking errors must prevent save
- Non-blocking warnings should still allow save
- Errors and warnings should identify exact field paths such as `analysis.transport` or `video.device_path`
- Typical messages should be concrete and user-readable, for example:
  - `video.device_path does not exist`
  - `analysis.transport must be shared_memory or dmabuf`
  - `fall_detection.pose_model_path is empty`

## Startup Script Changes

Update bundle runtime scripts so users no longer need to export large lists of runtime variables.

### Bundle contents

The bundle should include:

- `config/runtime_config.json`
- `scripts/start.sh`
- `scripts/start_all.sh`
- `scripts/stop.sh`
- `scripts/status.sh`
- `scripts/config.sh`

### `start.sh`

`start.sh` should:

- locate bundle root
- locate the default config file
- accept an optional `--config /path/to/runtime_config.json`
- export at most `RK_APP_CONFIG_PATH`
- stop exporting large sets of individual runtime settings for normal operation
- print the effective config file path in startup output

### `config.sh`

Add a dedicated script that launches `bin/health-config-ui` against the bundle's active config file so the user mental model becomes:

- configure: `./scripts/config.sh`
- run backend or full bundle: `./scripts/start.sh` or `./scripts/start_all.sh`
- stop: `./scripts/stop.sh`

## Compatibility Strategy

Preserve environment-variable compatibility during the migration so existing board-side workflows continue to work:

- benchmarking scripts can still force `RK_VIDEO_ANALYSIS_TRANSPORT=dmabuf`
- probe sessions can still force `RK_VIDEO_GST_FORCE_DMABUF_IO=1`
- tests can still use `qputenv(...)`

The key change is that service code no longer owns environment parsing; only the shared config layer does.

## Logging and Error Reporting

At startup, each service should log effective configuration with provenance. Example style:

- `video.pipeline_backend=inproc_gst source=config`
- `analysis.transport=dmabuf source=environment`
- `paths.database_path=/home/elf/rk3588_bundle/data/healthd.sqlite source=default`

If config loading fails:

- startup should stop early with a field-specific validation error
- `start.sh` should print a short human-readable failure summary
- `health-config-ui` should surface the same field-specific errors in the UI

## Migration Plan

Implement the change in four stages:

1. Add the shared runtime configuration module plus default `deploy/config/runtime_config.json`.
2. Convert `healthd`, `health-videod`, `health-falld`, and `health-ui` to consume typed config from the shared module while keeping env overrides.
3. Add standalone `health-config-ui` and bundle script integration.
4. Update README, bundle README, deployment docs, and runtime examples so the primary user workflow is JSON or config UI based instead of env export based.

## Testing and Verification

### Host verification

- Unit-test JSON parsing, defaults, path expansion, enum validation, and environment override precedence.
- Add focused tests for each service to confirm it receives config from the shared layer rather than direct env parsing.
- Add UI tests for `health-config-ui` covering load, edit, validate, save, and restore-default behavior.

### Bundle and cross-build verification

- Host build with `BUILD_TESTING=ON` must continue to pass.
- RK3588 bundle cross-build must package:
  - `config/runtime_config.json`
  - `bin/health-config-ui`
  - `scripts/config.sh`

### Board verification

- Verify bundle startup without manually exporting the current runtime variables.
- Verify full JSON-based startup for both a normal compatibility configuration and a zero-copy-oriented configuration.
- Verify env override precedence still works for board-side experiments.
- Verify `health-config-ui` can edit the bundle config on board and that saved changes affect the next startup.

## Success Criteria

The work is successful when:

- a normal user can configure the bundle without memorizing environment variables
- a single JSON file fully expresses the project's current runtime configuration surface
- a standalone Qt configuration application can edit and validate that file
- existing advanced env-based debugging and benchmarking workflows still work
- the board can still run both stable compatibility mode and advanced DMABUF mode through the new configuration system

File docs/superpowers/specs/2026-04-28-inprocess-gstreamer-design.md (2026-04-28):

# In-Process GStreamer Analysis Pipeline Design

## Goal

Replace the analysis side of `health-videod`'s external `gst-launch + fdsink` flow with an optional in-process GStreamer appsink path, so the daemon can eventually receive `GstBuffer` metadata and DMABUF fds directly instead of parsing raw bytes from stdout.

## Scope

- Add an opt-in runtime path selected by `RK_VIDEO_PIPELINE_BACKEND=inproc_gst`.
- Keep the current `gst-launch` path as the default and as a fallback.
- Implement preview + analysis first. Recording and snapshots remain on the current `gst-launch` commands.
- The in-process path must publish preview MJPEG on the same TCP URL and publish analysis frames through the existing `AnalysisFrameSource` interface.
- Analysis transport remains compatible with current shared-memory and DMABUF descriptor paths.

## Architecture

Add a small focused class under `rk_app/src/health_videod/pipeline/` that owns a `GstElement *pipeline`, a `GstElement *analysisSink`, and a GLib main context/thread. It builds a launch string equivalent to the current preview command, but uses `appsink name=analysis_sink` instead of `fdsink fd=1` for the analysis branch. The existing `GstreamerVideoPipelineBackend` chooses this class only when both the runtime env var is enabled and the binary was compiled with GStreamer app support.

Host builds do not have GStreamer development packages, so the GStreamer class is behind `RKAPP_ENABLE_INPROCESS_GSTREAMER`. Cross builds enable that option because the RK3588 sysroot has `gstreamer-1.0`, `gstreamer-app-1.0`, and `gstreamer-video-1.0` pkg-config files.

## Data Flow

Initial in-process path:

```text
v4l2src / filesrc
  -> tee
  -> preview branch: mppjpegenc -> multipartmux -> tcpserversink
  -> analysis branch: appsink
  -> GstSample map to bytes
  -> existing RGA converter or CPU RGB handling
  -> existing DMABUF/shared-memory publish path
```

This first implementation removes the external `gst-launch` process and stdout/fdsink boundary. If the `GstBuffer` exposes DMABUF memory, a later narrow patch can publish that fd directly without changing `health-falld`.

## Error Handling

- If in-process GStreamer is requested but the binary is not compiled with support, `startPreview()` returns a clear error and the caller can switch env/config back to default.
- If pipeline construction, state transition, appsink lookup, or bus error occurs, the backend reports `preview_pipeline_failed` through the existing observer path.
- `stopPreview()` tears down the Gst pipeline and joins its loop thread.

## Testing

- Host unit tests cover backend selection and unsupported-build error behavior without linking GStreamer.
- Existing pipeline command tests remain valid for the default `gst-launch` path.
- RK3588 cross-build verifies GStreamer symbols link.
- Board smoke test starts with `RK_VIDEO_PIPELINE_BACKEND=inproc_gst RK_VIDEO_ANALYSIS_TRANSPORT=dmabuf` and checks process status, video/fall perf, transport markers, and absence of crash/fatal logs.

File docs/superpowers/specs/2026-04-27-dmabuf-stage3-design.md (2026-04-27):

# DMABUF Stage 3 Feasibility And Probe Design

## Goal

Evaluate and then introduce DMA/DMABUF acceleration without destabilizing the current `health-videod -> shared memory -> health-falld` path. The first deliverable is a board-verified capability report and a sidecar probe. Mainline frame transport changes are only allowed after the probe proves format, stride, cache sync, fd lifetime, and RKNN compatibility on the RK3588 board.

## Current Baseline

The current `main` already uses RGA to produce pose-model-sized RGB analysis frames and `health-falld` uses those frames without CPU letterboxing. Board timing at 15 FPS shows pose `total_ms` around 23.7 ms, while stable ingest/infer FPS remains 15. The remaining likely performance opportunity is reducing cross-process frame payload movement and CPU/cache pressure, especially before increasing analysis FPS to 25.

## Recommended Approach

Use a three-step rollout:

1. **Capability probe only**: collect board facts for dma-heap devices, V4L2 DMABUF support, GStreamer DMABUF caps, RGA fd-buffer support, and RKNN `rknn_create_mem_from_fd` support. This step makes no production code changes.
2. **Sidecar DMABUF probe**: add a small debug/probe target or script that allocates/imports a DMA buffer, runs a controlled RGA operation against fd-backed memory, optionally imports the fd into RKNN, and reports timing/correctness. This must not replace the current production transport.
3. **Production transport**: after probe evidence, add a fallback-protected fd descriptor path. `health-videod` keeps a DMABUF pool, RGA writes model-ready frames into fd-backed buffers, and `health-falld` receives fds through Unix domain socket `SCM_RIGHTS` or an equivalent side channel. The current shared-memory payload ring remains the fallback.

## Non-Goals For The First Iteration

- Do not replace `SharedMemoryFrameRing` immediately.
- Do not require 25 FPS until the 15 FPS DMABUF probe is stable.
- Do not remove the existing byte-payload fallback.
- Do not couple the probe to UI preview transport.

## Success Criteria

- Board capability report documents available dma-heap nodes, GStreamer/V4L2 support, RGA fd-buffer behavior, and RKNN fd import behavior.
- Sidecar probe runs on RK3588 without crashing and prints enough timing/correctness evidence to compare against the existing path.
- Production code remains unchanged until probe evidence supports it.
- Any eventual production path has an explicit fallback to shared-memory payload transport and can be disabled through environment configuration.

## Risks

- GStreamer `gst-launch + fdsink fd=1` cannot transfer DMABUF file descriptors as ordinary stdout bytes; production fd passing likely requires an in-process GStreamer path or a helper that can pass fds over Unix sockets.
- RGA and RKNN may disagree on required format/stride/layout. RGB888 model input is simple, but fd-backed buffer stride and cache synchronization must still be verified.
- Full RKNN IO-memory was previously neutral or regressive in total pose timing, so importing DMABUF into RKNN must be measured rather than assumed beneficial.
- fd lifetime and pool reuse must be explicit to avoid use-after-close, leaks, or overwriting a frame while `health-falld` is still consuming it.

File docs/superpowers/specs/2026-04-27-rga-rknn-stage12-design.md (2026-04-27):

# RGA + RKNN Stage 1/2 Optimization Design

## Goal

Use the current `main` runtime as the performance baseline, then implement Scheme B: keep the existing process topology, have `health-videod` publish model-ready RGA-preprocessed RGB frames with letterbox metadata, and have `health-falld` use RKNN preallocated output buffers by default, with an opt-in full RKNN IO-memory path for board experiments.

## Baseline

Captured on RK3588 from `/home/elf/rk3588_bundle` before implementation:

- Commit/binaries: current `main` bundle, ARM aarch64 binaries.
- `start_all.sh` status: `healthd`, `health-videod`, `health-falld`, and `health-ui` all running.
- `video_perf`: stable at about `15.0 fps`, no dropped frames, one consumer.
- `fall_perf`: stable at about `15.0 ingest_fps` / `15.0 infer_fps`, `avg_infer_ms` around `24.2 ms`.
- Process snapshot after ~45s: `health-videod` about `2.5% CPU`, `health-falld` about `7.2% CPU`.
- Pose timing with `RK_FALL_POSE_TIMING_PATH=/tmp/rk_pose_timing_baseline.jsonl`, last 200 samples:
  - `preprocess_ms avg 0.0`
  - `inputs_set_ms avg 0.0`
  - `rknn_run_ms avg 21.61`
  - `outputs_get_ms avg 1.0`
  - `total_ms avg 23.77`

This baseline shows the current RGA RGB fast path already removes most CPU preprocessing cost. The realistic measurable win for Scheme B is primarily reducing output retrieval/copy overhead and preserving correct letterbox metadata for the model-ready frames.

## Scope

In scope:

- Add pose-preprocess metadata (`xPad`, `yPad`, `scale`, `preprocessedForPose`) to analysis packets/descriptors and shared-memory slots.
- Update the RGA converter so NV12 -> RGB can letterbox into the model input canvas instead of plain stretching.
- Let `health-falld` consume model-ready RGB packets directly with the metadata supplied by `health-videod`.
- Add RKNN output-buffer optimization in `RknnPoseEstimator`: preallocate output buffers during model load and pass them to `rknn_outputs_get` to avoid per-frame output allocation. Keep an opt-in `RK_FALL_RKNN_IO_MEM=zero_copy` path for full `rknn_set_io_mem` experiments.
- Keep fallback to the existing `rknn_inputs_set` / allocator-owned `rknn_outputs_get` path.
- Validate on RK3588 with the same bundle workflow and compare against the baseline metrics above.

Out of scope for this stage:

- Passing DMABUF fds between `health-videod` and `health-falld`.
- Replacing shared memory ring payloads with fd-backed frames.
- V4L2/GStreamer DMABuf caps negotiation and cache sync handling.

## Architecture

`health-videod` remains the owner of camera/GStreamer capture. Its analysis tap still emits NV12 frames from `gst-launch` stdout. The RGA converter receives the NV12 frame, fills a 640x640 RGB destination canvas with 114, resizes the source into a letterboxed ROI, and returns both the RGB payload and the letterbox metadata. The shared memory ring stores this metadata alongside the payload.

`health-falld` still receives descriptors over the local analysis stream and reads payload bytes from shared memory. If a packet is RGB, model-sized, and marked as pose-preprocessed, `RknnPoseEstimator` bypasses CPU letterbox and uses the provided metadata for post-processing coordinate restoration. If metadata is absent or invalid, it falls back to existing RGB/JPEG/NV12 preprocessing behavior.

For RKNN, `RknnPoseEstimator` initializes reusable output buffers when the real RKNN backend is enabled. On inference, it keeps the stable `rknn_inputs_set` / `rknn_run` path and asks `rknn_outputs_get` to write into those preallocated buffers. A full `rknn_set_io_mem` input/output path remains available with `RK_FALL_RKNN_IO_MEM=zero_copy`, but it is not the default because board measurements showed no better end-to-end timing. The default path targets the per-frame output allocation overhead without changing tensor layout semantics.

## Success Criteria

- Host tests pass and cover metadata serialization, shared-memory metadata preservation, RGA converter metadata propagation through the pipeline, and pose fast-path metadata consumption.
- RK3588 cross-build succeeds and produces ARM aarch64 binaries.
- Board `start_all.sh` launches all four services.
- Board runtime status still reports `input_connected=true`, `pose_model_ready=true`, `action_model_ready=true`, and `latest_state=monitoring`.
- Compared with baseline, pose timing should show `output_prealloc_path=true` and total pose `total_ms` should improve or at least not regress. The opt-in full IO-memory probe should show `io_mem_path=true` and `outputs_get_ms=0`, but it is only mergeable as default if it improves total timing.

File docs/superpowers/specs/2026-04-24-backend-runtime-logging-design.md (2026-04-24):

# Backend Runtime Logging Design

## Goal

Add sparse, actionable runtime and performance logs that help diagnose RK3588 video-analysis behavior without causing log spam. Logging should focus on backend processes (`health-videod`, `health-falld`). UI logging should remain limited to errors and connection changes.

## Scope

### In scope
- Add low-frequency aggregated performance summaries in `health-videod`
- Add low-frequency aggregated performance summaries in `health-falld`
- Keep immediate logging for important state transitions and failures
- Reduce or avoid per-frame steady-state logs that spam `tail -f`
- Keep UI logging restricted to errors and connection changes

### Out of scope
- Full metrics export system
- Prometheus or external telemetry backends
- Per-frame debug tracing by default
- New runtime configuration surface unless absolutely necessary

## Approach Options

### Option 1: event-only logging
Only log start/stop/error/state-change events.
- Pros: quietest logs
- Cons: weak performance visibility; hard to spot FPS drops or inference slowdown

### Option 2: event logs plus periodic summaries (recommended)
Log critical events immediately and emit compact summaries every fixed interval.
- Pros: good observability without spam; easy to inspect with `tail -f`
- Cons: slightly more state bookkeeping

### Option 3: verbose logs behind env flag
Keep default quiet and add a verbose mode for detailed traces.
- Pros: flexible for deep debugging
- Cons: extra complexity and still less useful in default mode for ongoing monitoring

## Recommended Design

Use immediate event logs for important state transitions and a 5-second periodic summary in backend services.

## health-videod logging

### Immediate logs
Log once per meaningful event:
- preview started/stopped
- recording started/stopped
- test input started/stopped
- test playback finished
- pipeline runtime error
- analysis ring init failure
- analysis output backend start/stop failure

### Periodic summary
Emit at most once every 5 seconds per active camera while frames are flowing:
- `camera_id`
- `input_mode`
- `analysis_frames_published`
- windowed publish FPS
- total ring dropped frames and window delta
- whether analysis consumers are connected
- current preview state

Format should be one compact line, e.g.:
`video_perf camera=front_cam mode=test_file state=previewing fps=12.4 published=62 dropped_total=0 dropped_delta=0 consumers=1`

## health-falld logging

### Immediate logs
Keep or add immediate logs for:
- ingest connected/disconnected
- pose model load success/failure
- action model load success/failure
- first classification after stream start
- `fall_event`
- newly observed runtime error or error cleared

### Reduce noisy logs
Current steady-state `classification` / `classification_batch` logs are too chatty.
Adjust behavior so that:
- `fall` and `lie` remain immediate
- stable `stand` / `monitoring` are not logged every frame
- periodic summary covers the steady-state operational picture

### Periodic summary
Emit at most once every 5 seconds while frames are flowing:
- input frame count in window
- ingest FPS
- infer FPS
- average infer latency in ms for the window
- frames with detected people
- frames without detected people
- non-empty classification batch count
- latest state/confidence
- latest error if present

Format should be one compact line, e.g.:
`fall_perf camera=front_cam ingest_fps=12.1 infer_fps=12.1 avg_infer_ms=31.8 people_frames=58 empty_frames=4 nonempty_batches=41 state=stand conf=0.99 error=`

## UI logging

Keep only:
- backend connect/disconnect
- preview socket errors
- fall backend connection changes

Do not add high-frequency UI-side classification logs.

## Implementation Plan Shape

### Shared pattern
Implement lightweight in-process aggregators using counters and `QElapsedTimer` or timestamps.
No extra threads or locks are needed because the relevant callbacks already run on the owning Qt thread.

### `health-videod`
- add a small stats struct in the pipeline backend or service layer
- update counters when analysis descriptors are published
- flush a summary only when 5 seconds have elapsed and there has been activity
- reset only window counters, not lifetime counters

### `health-falld`
- add a small stats struct in `FallDaemonApp`
- update counters per received frame and per completed inference
- accumulate inference duration as `lastInferTs - frame-processing-start`
- count people/no-people frames and non-empty batch publications
- flush summary every 5 seconds when active

### log suppression behavior
- deduplicate repeated runtime errors by only logging when the error value changes
- only log error-clear transitions once
- only emit periodic summary when the window had activity

## Testing Strategy

### Automated
- add focused unit tests for summary throttling behavior where practical
- verify repeated high-frequency updates do not emit every call
- verify summary emits after interval elapses
- verify stale-state logs (e.g. repeated `stand`) are suppressed if implemented through helper logic

### Manual
Board verification in test mode using `/home/elf/Videos/video.mp4`:
- confirm `health-videod.log` shows start/stop events and low-frequency `video_perf`
- confirm `health-falld.log` shows low-frequency `fall_perf`
- confirm logs do not print one `stand` line per frame anymore
- confirm `fall` events still appear immediately when present

## Risks
- too little logging may hide rare transitions
- too much aggregation may hide short spikes
- timestamps based on wall clock should only be used for summaries, not correctness

## Mitigations
- keep critical transitions immediate
- keep summary interval short enough (5s) for interactive debugging
- preserve existing latency marker files for deeper measurement workflows

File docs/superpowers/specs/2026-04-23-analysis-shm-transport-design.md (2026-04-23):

# Analysis Shared-Memory Transport Design

## Goal

Replace the current large-frame analysis transport path between `health_videod` and `health_falld` with a shared-memory ring buffer while keeping a Unix domain socket as the notification/control channel. The new design reduces copies, removes large payload transfer over the socket, preserves the current "latest frame wins" behavior, and does not include a rollback or dual-transport compatibility mode.

## Current State

The current analysis chain works like this:

1. `GstreamerVideoPipelineBackend` runs `gst-launch` as a subprocess.
2. The analysis branch emits fixed-size RGB frames to `fdsink fd=1`.
3. `health_videod` reads subprocess `stdout`, reconstructs whole frames, and stores them in `AnalysisFramePacket::payload`.
4. `GstreamerAnalysisOutputBackend` serializes each packet and writes the full payload to a `QLocalSocket`.
5. `health_falld` reads the socket, deserializes the packet, and forwards it to pose inference.

This path performs unnecessary copies and serializes large frame payloads through the socket even though the runtime semantics only care about the newest frame.

## Constraints

- Keep the existing `gst-launch` subprocess approach for now.
- Keep Unix domain sockets for connection management and frame-arrival notification.
- Do not introduce a rollback path, feature flag, or socket-payload fallback.
- Preserve the current upper-layer API in `health_falld`: inference still receives `AnalysisFramePacket`.
- Prefer dropping stale frames over blocking the producer.
- Scope the transport redesign to the analysis IPC boundary; avoid refactoring inference and tracking layers.

## Decision Summary

Use a per-camera POSIX shared-memory ring buffer for frame payloads and a lightweight Unix socket message carrying only frame descriptors. `health_videod` writes raw frame bytes into shared memory, then sends a descriptor over the socket. `health_falld` receives the descriptor, validates the referenced slot, reconstructs an `AnalysisFramePacket` from shared memory, and emits it to the existing processing pipeline.

## Architecture

### Producer Side

`health_videod` keeps its current GStreamer subprocess and `stdout` read path. After assembling a complete RGB frame from `stdout`, it writes the frame into a shared-memory slot rather than embedding the payload into a socket packet.

The producer side consists of:

- `GstreamerVideoPipelineBackend`: still owns subprocess startup and `stdout` frame assembly.
- `SharedMemoryFrameRingWriter`: new component that owns `shm_open`, `ftruncate`, `mmap`, slot layout, and write-side sequencing.
- `GstreamerAnalysisOutputBackend`: changed to send only lightweight descriptors over `QLocalSocket`.

### Consumer Side

`health_falld` keeps the existing socket connection model. The socket now carries a descriptor instead of a full frame payload. The consumer uses that descriptor to read the frame from shared memory and then emits a normal `AnalysisFramePacket` upstream.

The consumer side consists of:

- `AnalysisStreamClient`: still owns socket connection, reconnect, and read buffering, but now decodes descriptors.
- `SharedMemoryFrameRingReader`: new component that opens/maps the producer ring and reconstructs `AnalysisFramePacket`.
- Existing pose / tracking / classification layers remain unchanged.

## Shared Memory Layout

Each camera gets its own POSIX shared-memory object named from the camera id, for example:

- `/rk_video_analysis_front_cam`

The mapped region is organized as:

```text
[SharedHeader][Slot 0][Slot 1]...[Slot N-1]
```

The global header stores stable layout metadata:

```cpp
struct SharedHeader {
    quint32 magic;
    quint16 version;
    quint16 slotCount;
    quint32 slotStride;
    quint32 maxFrameBytes;
    quint32 producerPid;
    quint64 publishedFrames;
    quint64 droppedFrames;
};
```

Each slot has a fixed-size header followed by a fixed-size byte region:

```cpp
struct FrameSlotHeader {
    quint64 sequence;
    quint64 frameId;
    qint64 timestampMs;
    qint32 width;
    qint32 height;
    qint32 pixelFormat;
    quint32 payloadBytes;
    quint32 flags;
};
```

Each slot is laid out as:

```text
[FrameSlotHeader][raw frame bytes padded to slotStride]
```

### Layout Rules

- `slotStride` is fixed for the entire ring.
- `maxFrameBytes` is fixed for the entire ring.
- The initial implementation targets the current producer output: `RGB 640x640`, so `maxFrameBytes = 640 * 640 * 3`.
- `slotCount` defaults to `4`.
- The producer uses a simple circular overwrite policy. When the ring wraps, the oldest unread slot may be overwritten.

## Descriptor Protocol

The Unix socket no longer carries frame payload bytes. It carries only a lightweight descriptor:

```cpp
struct AnalysisFrameDescriptor {
    quint64 frameId;
    qint64 timestampMs;
    QString cameraId;
    qint32 width;
    qint32 height;
    AnalysisPixelFormat pixelFormat;
    quint32 slotIndex;
    quint64 sequence;
    quint32 payloadBytes;
};
```

This message is enough for the consumer to locate and validate the corresponding frame in shared memory.

### Protocol Rules

- Descriptor messages use a dedicated encoder/decoder rather than reusing `analysis_stream_protocol`.
- `analysis_stream_protocol` remains the internal full-frame packet representation used above the ingest boundary.
- The descriptor protocol must be versioned independently from the old packet transport.
- Descriptor delivery is best-effort. A descriptor may legitimately reference a slot that has already been overwritten by the time the consumer reads it; that frame is dropped.

## Synchronization Model

The transport is optimized for one producer and one primary consumer per camera, without blocking the producer.

### Producer Write Order

For each new frame:

1. Select the next slot in round-robin order.
2. Copy payload bytes into the slot's byte region.
3. Write the non-sequence slot header fields.
4. Publish the final `sequence` value last.
5. Send the descriptor over the Unix socket.

### Consumer Read Validation

For each descriptor:

1. Read the slot header `sequence`.
2. If it does not match the descriptor `sequence`, drop the frame.
3. Copy header fields and payload bytes into a local `AnalysisFramePacket`.
4. Re-read `sequence`.
5. If the two sequence reads differ, drop the frame because the slot was rewritten mid-read.

This avoids per-frame locks and is consistent with the current "latest frame wins" semantics.

## Data Flow

### Producer Path

1. `GstreamerVideoPipelineBackend` receives bytes from subprocess `stdout`.
2. Once one RGB frame has been assembled, it creates a producer-side frame view.
3. `SharedMemoryFrameRingWriter` writes the frame into the next slot and returns:
   - `slotIndex`
   - `sequence`
   - `payloadBytes`
4. `GstreamerAnalysisOutputBackend` sends an `AnalysisFrameDescriptor` to connected clients.

### Consumer Path

1. `AnalysisStreamClient` receives a descriptor from the socket.
2. `SharedMemoryFrameRingReader` opens/maps the named ring if needed.
3. The reader validates the slot using `slotIndex + sequence`.
4. If valid, it reconstructs an `AnalysisFramePacket`.
5. `AnalysisStreamClient` emits `frameReceived(const AnalysisFramePacket&)`.

### Runtime Semantics

- Slow consumers may miss frames.
- The newest valid frame is preferred over ordered delivery guarantees.
- Producer throughput must not depend on consumer throughput.

## Component Changes

### New Files

- `rk_app/src/health_videod/analysis/shared_memory_frame_ring.h`
- `rk_app/src/health_videod/analysis/shared_memory_frame_ring.cpp`
- `rk_app/src/health_falld/ingest/shared_memory_frame_reader.h`
- `rk_app/src/health_falld/ingest/shared_memory_frame_reader.cpp`
- `rk_app/src/shared/protocol/analysis_frame_descriptor_protocol.h`
- `rk_app/src/shared/protocol/analysis_frame_descriptor_protocol.cpp`

### Modified Files

- `rk_app/src/health_videod/pipeline/gstreamer_video_pipeline_backend.h`
- `rk_app/src/health_videod/pipeline/gstreamer_video_pipeline_backend.cpp`
- `rk_app/src/health_videod/analysis/analysis_output_backend.h`
- `rk_app/src/health_videod/analysis/gstreamer_analysis_output_backend.h`
- `rk_app/src/health_videod/analysis/gstreamer_analysis_output_backend.cpp`
- `rk_app/src/health_falld/ingest/analysis_stream_client.h`
- `rk_app/src/health_falld/ingest/analysis_stream_client.cpp`
- `rk_app/src/health_falld/runtime/runtime_config.h`
- `rk_app/src/health_falld/runtime/runtime_config.cpp`
- `rk_app/src/shared/models/fall_models.h`
- relevant `CMakeLists.txt` files in `rk_app/src/shared`, `rk_app/src/health_videod`, `rk_app/src/health_falld`, and `rk_app/src/tests`

## Model Changes

Introduce a dedicated descriptor model instead of overloading `AnalysisFramePacket`:

```cpp
struct AnalysisFrameDescriptor {
    quint64 frameId = 0;
    qint64 timestampMs = 0;
    QString cameraId;
    qint32 width = 0;
    qint32 height = 0;
    AnalysisPixelFormat pixelFormat = AnalysisPixelFormat::Jpeg;
    quint32 slotIndex = 0;
    quint64 sequence = 0;
    quint32 payloadBytes = 0;
};
```

`AnalysisFramePacket` remains unchanged and continues to represent a fully materialized frame for upper layers.

## Writer Responsibilities

`SharedMemoryFrameRingWriter` is responsible for:

- creating/opening the named shared-memory object
- sizing and mapping the region
- initializing the header
- validating payload size against `maxFrameBytes`
- selecting the next slot
- writing the slot payload and header
- tracking producer-side counts such as `publishedFrames` and `droppedFrames`
- exposing enough metadata for `GstreamerAnalysisOutputBackend` to build descriptors

The writer must not depend on `QLocalSocket` or descriptor encoding.

## Reader Responsibilities

`SharedMemoryFrameRingReader` is responsible for:

- deriving the shared-memory name from the camera id
- opening and mapping the region lazily
- validating header magic/version/layout
- validating slot index, payload size, frame shape, and sequence
- reconstructing an `AnalysisFramePacket`
- remapping when producer identity or layout changes

The reader must not know about pose inference; it stops at producing a valid `AnalysisFramePacket`.

## Runtime Configuration

The first implementation uses fixed defaults:

- shm name derived from camera id
- `slotCount = 4`
- `maxFrameBytes = 640 * 640 * 3`

Add explicit config fields only where runtime discovery is necessary, such as:

- optional shared-memory name override in `FallRuntimeConfig`

Do not add a transport mode switch because rollback is out of scope.

## Error Handling

### Producer Errors

- If shared memory cannot be created or mapped, mark analysis output unavailable and surface an error in `AnalysisChannelStatus::lastError`.
- If a frame exceeds `maxFrameBytes`, drop it and increment `droppedFrames`.
- If no socket clients are connected, producer may continue writing to shared memory, but descriptor publication becomes a no-op.

### Consumer Errors

- If the shared-memory object does not exist yet, wait for later descriptors and retry lazily.
- If header magic/version/layout is invalid, mark input disconnected and retry on subsequent descriptors.
- If the referenced slot has already been overwritten, drop the frame silently.
- If payload size or pixel-format metadata is invalid, drop the frame and surface a non-fatal runtime error.

### System Behavior

- Frame loss is acceptable.
- Producer blocking is not acceptable.
- A single corrupt frame must not tear down the whole ingest pipeline.

## Multi-Consumer Behavior

The transport is optimized around one analysis consumer, but multiple socket clients may still connect. Shared memory is read-only for consumers, so multiple readers are safe as long as each reader accepts possible frame overwrite. No per-consumer acknowledgment or reference counting is added in this design.

## Testing Strategy

### Unit Tests

- shared-memory writer creates and initializes the ring correctly
- reader validates magic/version/layout
- writer/reader round-trip one frame successfully
- descriptor pointing to an overwritten slot is rejected
- sequence mismatch during read causes frame drop
- invalid payload size is rejected

### Protocol Tests

- descriptor encode/decode round-trip
- malformed descriptor rejection
- invalid slot index rejection

### Integration Tests

- `health_videod` writes a frame to shared memory and publishes a descriptor
- `health_falld` receives the descriptor and reconstructs a matching `AnalysisFramePacket`
- slow-consumer scenario proves old descriptors can be dropped without blocking
- producer restart/remap scenario proves the reader can recover

### Regression Tests

- update `analysis_stream_client_test` to the descriptor + shm model
- update video daemon analysis backend tests to verify descriptor publication instead of full-payload publication
- keep end-to-end fall daemon tests asserting that inference still receives correct RGB frames

### Performance Baseline

Performance validation is a required part of this design, not an optional follow-up. The transport change is intended to improve runtime behavior relative to the current socket-payload transport on the current `main` branch, so testing must include an explicit before/after comparison.

Use the current `main` branch as the baseline implementation and compare it against the shared-memory design implementation under the same input conditions. The comparison should use the same RK3588 hardware, the same test media, the same camera/test-mode settings, and the same model assets.

At minimum, collect and compare:

- end-to-end frame delivery latency from `health_videod` publish point to `health_falld` ingest point
- first-frame-to-first-inference latency in test mode
- steady-state analysis FPS observed by `health_falld`
- producer-side dropped-frame count
- producer CPU usage for `health-videod`
- consumer CPU usage for `health_falld`

Where available, also record pose-stage timings already exposed by the runtime, especially preprocess time. Because the new design removes large socket payload transport, the expected result is that the shared-memory implementation is no worse than `main` on all headline metrics and measurably better on at least frame-delivery overhead, dropped-frame behavior under load, or CPU cost.

The performance test plan should produce a checked-in result note documenting:

- baseline commit on `main`
- test commit for the shared-memory design
- hardware and runtime environment
- commands used to run the comparison
- raw measurements
- a short conclusion stating whether the design delivered the expected improvement

## Migration Plan

1. Add shared-memory ring and descriptor protocol primitives with tests.
2. Integrate the writer into `health_videod` after `stdout` frame assembly.
3. Change `GstreamerAnalysisOutputBackend` to publish descriptors only.
4. Integrate the reader into `health_falld` and keep `frameReceived(AnalysisFramePacket)` unchanged.
5. Update integration and end-to-end tests.
6. Remove any now-dead assumptions that the analysis socket carries full frame payloads.

## Non-Goals

- replacing `gst-launch` with in-process GStreamer
- DMA-BUF or kernel-level zero-copy
- transport rollback, dual-stack support, or runtime transport selection
- changing upper-layer pose/action inference interfaces
- guaranteed delivery of every analysis frame

## Open Choices Already Resolved

- Keep Unix socket as control/notification path: yes.
- Move only frame payload bytes to shared memory: yes.
- Preserve "latest wins" semantics: yes.
- Exclude rollback path: yes.
- Keep inference-side API stable: yes.

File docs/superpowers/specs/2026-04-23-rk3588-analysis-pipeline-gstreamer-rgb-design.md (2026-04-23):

# RK3588 Analysis Pipeline GStreamer RGB Design

Date: 2026-04-23
Status: Approved design
Scope: RK3588 fall-analysis pipeline only

## Goal

Restore product-grade fall-analysis startup latency by moving the expensive image preprocessing work out of `health-falld` and into the `health-videod` GStreamer analysis branch, while keeping the UI preview pipeline unchanged.

## Non-Goals

- Do not change the UI preview chain or its MJPEG transport behavior.
- Do not merge processes or reduce service isolation between `health-videod` and `health-falld`.
- Do not introduce DMABUF/shared-buffer transport in this version.
- Do not redesign the RKNN pose model itself.

## Problem Statement

The current candidate pipeline replaced the old JPEG analysis path with an NV12 raw path, but real-board measurements show worse startup latency than `main`.

Measured board-side evidence:

- `main` first useful classification: about 1.8s
- current candidate first useful classification: about 4.2s
- `main` pose preprocess: about 5-6 ms/frame
- current candidate pose preprocess: about 60 ms/frame

This proves the main regression is not in LSTM classification and not in RKNN runtime execution itself. The dominant regression is the CPU-side preprocessing now performed in `health-falld`, specifically the `NV12 -> RGB + resize + letterbox` path.

The current candidate architecture gets raw frames earlier, but it does not inject them into YOLO in a model-friendly format. Instead, it forwards NV12 into `health-falld`, where the service performs a slow CPU preprocessing step. As a result, the intended raw-path benefit is lost.

## Design Summary

Adopt a GStreamer-first preprocessing design for the fall-analysis branch:

- `health-videod` keeps the current MJPEG preview branch for the UI.
- `health-videod` adds or refines a dedicated analysis branch that outputs fixed-size RGB raw frames suitable for direct RKNN pose input.
- `health-falld` consumes those RGB frames over the existing analysis socket and injects them into the pose model with minimal additional work.
- `health-falld` no longer performs the default NV12 preprocessing path for the production analysis pipeline.

This preserves process independence while moving the heavy image manipulation into the multimedia pipeline where it belongs.

## Architecture

### Current `main`

1. `health-videod` produces MJPEG/JPEG for preview and analysis transport.
2. `health-falld` decodes JPEG and converts it into the pose model input.
3. Startup classification latency is acceptable.

### Current candidate

1. `health-videod` taps NV12 frames from the preview pipeline.
2. `health-falld` performs NV12 preprocessing on CPU.
3. Startup classification latency regresses badly.

### New design

1. `health-videod` keeps the preview branch untouched:
   - preview remains MJPEG over TCP for the UI.
2. `health-videod` runs a dedicated analysis branch:
   - decode or camera source
   - colorspace conversion in GStreamer
   - scaling in GStreamer
   - fixed analysis FPS in GStreamer
   - output fixed-size RGB raw frames
3. `health-videod` publishes RGB analysis frames over the existing analysis transport.
4. `health-falld` consumes fixed-size RGB frames and uses a thin input path into RKNN.

## Service Responsibilities

### `health-videod`

Responsible for:

- sourcing camera/test-file frames
- preserving the UI preview path as-is
- preparing analysis frames in a pose-model-friendly RGB format
- rate-limiting analysis FPS to a stable value
- publishing analysis frames through the existing IPC channel

Not responsible for:

- fall classification
- RKNN pose inference
- UI preview rendering logic beyond current behavior

### `health-falld`

Responsible for:

- receiving RGB analysis frames
- thin validation of frame payload shape
- RKNN pose inference
- post-processing detections into tracked people
- LSTM/rule-based action classification

Not responsible for:

- default production-path NV12 preprocessing
- MJPEG/JPEG parsing for the new analysis path

## Data Contract

The existing `AnalysisFramePacket` remains the IPC unit, but the default production analysis payload changes to RGB raw.

Expected analysis payload for the new path:

- `pixel_format = rgb`
- `width = pose_input_width`
- `height = pose_input_height`
- `payload.size() == width * height * 3`

The protocol layer must reject malformed RGB packets.

## Detailed Design

### 1. Keep UI preview unchanged

The current preview TCP MJPEG branch remains the UI source of truth. No UI-facing API or transport semantics change in this design.

This avoids destabilizing preview latency or breaking existing dashboard behavior while work is focused on fall analysis.

### 2. Move image preprocessing into GStreamer

The analysis branch should be refactored so GStreamer performs the expensive per-frame operations that are currently happening inside `health-falld`.

Target operations in GStreamer:

- decode if source is test file
- colorspace conversion to RGB
- scaling to the pose model input dimensions
- stable analysis frame-rate limiting

Preferred first version:

- output RGB raw frames already matching the RKNN pose model input width and height
- remove the need for `health-falld` to perform per-pixel NV12 conversion in the default path

### 3. Thin RGB input path in `health-falld`

`health-falld` should add a fast RGB path in `rknn_pose_estimator.cpp`:

- validate RGB payload size and dimensions
- inject RGB payload directly into `rknn_inputs_set`
- avoid CPU image conversion for the production path

The old NV12 preprocessing code may remain in the repository for fallback/testing, but it should no longer be the default analysis path once the new pipeline is enabled.

### 4. Protocol support for RGB

`analysis_stream_protocol.cpp` currently validates known pixel formats and payload shapes. It must be extended or finalized to support RGB payloads explicitly and reject inconsistent frame shapes.

This keeps the cross-process boundary strict and debuggable.

## Performance Intent

This design does not claim zero-copy transport. It is instead a targeted correction of where preprocessing work happens.

Expected gain comes from:

- replacing slow CPU-side NV12 preprocessing in `health-falld`
- leveraging GStreamer pipeline elements for colorspace conversion and scaling
- keeping `health-falld` focused on inference and classification

Primary success target:

- candidate startup classification latency is no worse than `main`

Secondary target:

- reduce `health-falld` pose preprocess time from about 60 ms/frame toward the `main` baseline range

## Validation Plan

### Local validation

- protocol tests for RGB payload encode/decode and size validation
- pipeline-construction tests verifying the analysis branch outputs fixed-size RGB raw frames
- pose-estimator tests verifying RGB fast-path behavior does not require NV12 preprocessing

### Board validation

Use the same board and input file already used for regression testing:

- board: RK3588 development board
- input: `/home/elf/Videos/video.mp4`
- start mode: existing `start_test_input` path

Capture and compare:

- startup classification latency
- first useful state (`monitoring`, `stand`, etc.)
- pose-stage timing breakdown:
  - preprocess
  - `rknn_inputs_set`
  - `rknn_run`
  - `rknn_outputs_get`
  - post-process

Acceptance condition for this version:

- candidate startup classification latency is no worse than `main` on real hardware

## Risks

### Risk: fixed-size RGB transport increases payload size

RGB frames are larger than JPEG payloads. Even with that, this design is still expected to outperform the current NV12 path because it removes the dominant 60 ms/frame CPU preprocessing bottleneck.

### Risk: letterbox handling mismatch

If the pose model requires exact letterbox semantics that are not fully reproduced in GStreamer, accuracy could drift. The implementation must either:

- fully match the required preprocessing geometry in GStreamer, or
- leave only a tiny geometry/padding step in `health-falld`

### Risk: analysis FPS chosen poorly

If analysis FPS is too low, startup latency remains poor. If too high, downstream inference may overload. The implementation should begin with a stable analysis FPS chosen to match or beat `main` startup latency.

## Why This Version Stops Here

This design intentionally does not include shared buffers or DMABUF direct-consumption work. Those may still be worthwhile later, but they are not required to answer the current product need:

- restore analysis responsiveness
- preserve service isolation
- avoid destabilizing the preview/UI chain

## File-Level Impact Direction

Likely affected areas in the implementation plan:

- `rk_app/src/health_videod/pipeline/gstreamer_video_pipeline_backend.cpp`
- `rk_app/src/health_videod/pipeline/gstreamer_video_pipeline_backend.h`
- `rk_app/src/health_videod/analysis/gstreamer_analysis_output_backend.cpp`
- `rk_app/src/health_videod/analysis/gstreamer_analysis_output_backend.h`
- `rk_app/src/shared/protocol/analysis_stream_protocol.cpp`
- `rk_app/src/health_falld/pose/rknn_pose_estimator.cpp`
- `rk_app/src/health_falld/pose/rknn_pose_estimator.h`
- targeted tests under `rk_app/src/tests/video_daemon_tests/`
- targeted tests under `rk_app/src/tests/fall_daemon_tests/`

## Decision

Approved approach for implementation:

- Use GStreamer-side preprocessing for the analysis branch.
- Keep UI preview unchanged.
- Maintain `health-videod` / `health-falld` process isolation.
- Treat RGB fixed-size analysis frames as the new default production path for pose inference in this version.

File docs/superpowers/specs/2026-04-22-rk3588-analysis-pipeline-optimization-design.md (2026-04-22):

## RK3588 Analysis Pipeline Optimization Design

Date: 2026-04-22
Status: Approved for planning

## 1. Goal

Optimize the RK3588 camera-to-fall-detection path so the fall-analysis service no longer depends on the UI preview MJPEG stream.

This design intentionally keeps the current UI preview transport unchanged in this phase. The optimization target is the analysis data path only.

The desired outcome is:

- preserve independent backend services
- preserve `health-videod` as the single owner of the camera device
- remove the unnecessary `raw -> JPEG -> decoded image -> model input` round-trip from the fall-analysis path
- improve latency, CPU efficiency, and runtime stability for fall detection

Out of scope for this version:

- redesigning the UI preview path
- replacing the current `health-ui` preview consumer
- DMABUF preview rendering in the UI
- camera-driver changes in the kernel
- multi-camera generalization

## 2. User-Approved Scope

The user explicitly approved the following direction during discussion:

- treat the current performance problem as an architecture problem in the user-space media pipeline, not as a kernel camera-driver problem
- document the existing design problem in detail
- document the optimization plan in detail
- keep backend components independent
- keep the current UI preview solution unchanged in this phase
- prioritize fixing the fall-analysis data path

## 3. Existing Context

The current video stack is already split into independent services:

- `health-videod`
  - the only process allowed to open `/dev/video11`
  - manages preview, recording, and snapshot
  - exposes video control/status IPC
- `health-ui`
  - uses the local video control/status IPC
  - consumes preview frames from a local MJPEG TCP stream
- `health-falld`
  - consumes analysis frames from `health-videod`
  - runs pose estimation and fall classification

Current default camera path:

- camera id: `front_cam`
- device path: `/dev/video11`
- preview profile: `640x480`, `NV12`, `30fps`
- record profile: `1280x720`, `NV12`, `30fps`
- snapshot profile: `1920x1080`, `NV12`

Important architectural fact:

- the camera device is correctly single-owned by `health-videod`
- the main design problem is how `health-videod` currently exports frames to the analysis service

## 4. Problem Statement

### 4.1 What the fall-analysis service actually needs

The fall-analysis service does not fundamentally need JPEG images.

Its real requirement is an inference-friendly frame input, such as:

- `NV12`
- `RGB`
- another uncompressed or near-uncompressed frame representation suitable for preprocessing

The current pose path in `health-falld` ultimately converts the incoming payload into a model input buffer. That means compressed JPEG is not the natural working format for inference.

### 4.2 What the current system actually does

The current preview pipeline in `health-videod` is effectively:

```text
v4l2src -> video/x-raw,format=NV12 -> jpegenc -> multipartmux -> tcpserversink
```

This means the frame already exists as uncompressed `video/x-raw, format=NV12` before `jpegenc` runs.

However, the current analysis output path does not branch off at that point. Instead, it reuses the preview output behavior:

1. `health-videod` encodes preview frames to JPEG
2. `health-videod` exposes them as local `tcp_mjpeg`
3. the analysis output backend reconnects to that preview URL
4. it parses the multipart MJPEG stream again
5. it extracts JPEG payload bytes
6. it repackages those JPEG bytes into `AnalysisFramePacket`
7. `health_falld` receives the packet
8. `health_falld` decodes JPEG into `QImage`
9. `health_falld` converts to `RGB888`
10. `health_falld` performs letterboxing and copies the data again into the RKNN input buffer

So the current analysis path is not:

```text
camera raw frame -> analysis preprocess -> inference
```

It is:

```text
camera raw frame -> JPEG preview encode -> MJPEG transport -> JPEG decode -> preprocess -> inference
```

### 4.3 Why this is a design problem

The existing architecture makes the analysis path depend on a preview-oriented transport format.

That is wrong for three reasons:

1. Preview and analysis have different data needs
   - preview needs a display-friendly transport
   - analysis needs an inference-friendly transport
2. The preview format was chosen for UI consumption convenience, not for model efficiency
3. Analysis becomes indirectly coupled to preview behavior, even though preview is not its real upstream dependency

This is therefore not a simple local inefficiency. It is a data-plane design error.

### 4.4 Observable consequences

The current design adds avoidable costs:

- JPEG encode in `health-videod`
- local TCP transport overhead
- multipart parsing overhead
- repeated `QByteArray` append/remove/slice activity
- JPEG decode in `health_falld`
- image format conversion in `health_falld`
- extra packing copy into the RKNN input buffer

The likely runtime effects are:

- increased fall-detection latency
- increased CPU usage
- reduced headroom during simultaneous preview + record + infer workloads
- more brittle coupling between video preview behavior and analytics behavior

## 5. Source-Level Evidence

The design problem is directly visible in the current source tree.

### 5.1 Preview pipeline encodes raw frames into JPEG

`rk_app/src/health_videod/pipeline/gstreamer_video_pipeline_backend.cpp`

- `buildPreviewCommand()` constructs:
  - `v4l2src`
  - `video/x-raw,format=NV12`
  - `jpegenc`
  - `multipartmux`
  - `tcpserversink`

This confirms the uncompressed frame exists before JPEG encoding.

### 5.2 Analysis output reconnects to the preview stream

`rk_app/src/health_videod/analysis/gstreamer_analysis_output_backend.cpp`

- `configurePreviewSource()` validates `transport=tcp_mjpeg`
- `previewSocket_` connects to the preview host/port
- `processPreviewChunk()` reparses multipart MJPEG
- `broadcastFrame()` repackages the extracted JPEG into `AnalysisFramePacket`

This confirms the analysis path is derived from preview output instead of directly from the capture path.

### 5.3 Fall analysis decodes JPEG back into an image buffer

`rk_app/src/health_falld/pose/rknn_pose_estimator.cpp`

- `QImage::fromData(frame.payload, "JPEG")`
- `convertToFormat(QImage::Format_RGB888)`
- letterboxing into a new image
- another packed buffer copy for RKNN input

This confirms the system pays the full JPEG decode and repack cost before inference.

## 6. Design Principles for the Fix

The optimization must satisfy the following non-negotiable principles:

1. Camera ownership remains inside `health-videod`
2. `health-ui` remains independent and unchanged in this phase
3. `health-falld` remains an independent service
4. The analysis path must no longer depend on preview transport
5. Recording must remain independent of analysis health
6. Failure in the analysis pipeline must not break preview or recording

## 7. Approaches Considered

### Recommended: introduce a dedicated analysis frame branch in `health-videod`

Summary:

- keep the current preview pipeline for UI unchanged
- add a separate analysis output path in `health-videod`
- analysis frames come from pre-JPEG raw video frames, not from the preview MJPEG stream

Pros:

- directly fixes the architectural error
- preserves component independence
- avoids destabilizing the UI preview in this phase
- gives immediate latency and CPU benefits on the fall-analysis path
- keeps future room for later transport upgrades

Cons:

- requires redesign of the analysis frame export path
- requires changes to both `health-videod` and `health-falld`

### Alternative: keep MJPEG preview and only optimize JPEG decode in `health_falld`

Pros:

- smallest code change

Cons:

- does not fix the root cause
- preview and analysis remain incorrectly coupled
- still pays the JPEG encode cost in the upstream path

### Alternative: full shared-buffer or DMABUF redesign now

Pros:

- highest long-term performance ceiling

Cons:

- too large for the current phase
- would unnecessarily mix the urgent analysis fix with a UI transport redesign
- increases delivery and stability risk for this iteration

## 8. Recommended Architecture

### 8.1 High-Level Design

Keep the current preview path unchanged and create a dedicated analysis branch:

```text
/dev/video11
   |
   v
health-videod
   |- preview path    -> existing tcp_mjpeg -> health-ui
   |- record path     -> existing h264/mp4 output
   `- analysis path   -> dedicated analysis frame output -> health-falld
```

The key change is that the analysis path branches from the capture side before JPEG preview encoding.

### 8.2 What changes conceptually

Old model:

- preview output is treated as the source for analysis

New model:

- preview output and analysis output are sibling consumers of the same captured frame source

That restores a correct separation of concerns:

- preview is for human display
- analysis is for inference

## 9. Analysis Data Path Design

### 9.1 Capture-side branch point

The dedicated analysis path must branch from the uncompressed frame path before `jpegenc`.

The most important rule is:

- analysis output must not be produced by reconnecting to `previewUrl`

Instead, `health-videod` must produce analysis frames directly from the capture pipeline.

### 9.2 Analysis transport format

For this phase, the analysis transport should carry uncompressed frame content, not JPEG.

Recommended starting point:

- `NV12`

Why `NV12`:

- it already matches the current capture-side caps in the existing video pipeline
- it avoids the JPEG encode/decode round-trip
- it keeps the path closer to the hardware-native video flow

The protocol must explicitly identify:

- width
- height
- pixel format
- payload size
- timestamp
- frame id

### 9.3 Analysis transport protocol

Retain the current idea of a dedicated high-frequency analysis stream between `health-videod` and `health-falld`, but change its payload semantics.

Suggested packet model:

```text
AnalysisFramePacket
- magic/version
- frame_id
- timestamp_ms
- camera_id
- width
- height
- pixel_format
- payload_size
- payload_bytes
```

For this design phase:

- `pixel_format` must no longer imply `JPEG` only
- `NV12` must become a supported first-class transport format

### 9.4 Delivery policy

Analysis is a real-time consumer, not an archival consumer.

Recommended policy:

- keep only the latest frame if the analysis service falls behind
- do not build unbounded frame queues
- prefer frame dropping over pipeline backpressure that could damage preview or recording

This must be explicit in the implementation strategy.

## 10. health-videod Changes

`health-videod` keeps camera ownership and adds a dedicated analysis export responsibility.

Required design changes:

- stop deriving analysis from `previewUrl`
- introduce a true analysis source inside the capture pipeline
- emit `AnalysisFramePacket` from that dedicated source
- preserve current preview and record behavior

`health-videod` must continue to treat analysis as optional:

- if no analysis client is connected, preview and recording still work
- if analysis export fails, preview and recording still work

## 11. health-falld Changes

`health_falld` must change its ingest expectation from `JPEG image payload` to `inference-oriented frame payload`.

Required design changes:

- `AnalysisStreamClient` continues to receive `AnalysisFramePacket`
- the estimator path must accept `NV12` input
- preprocessing must convert from the new packet format to the model input format

This still allows preprocessing copies where needed, but it removes the most wasteful encode/decode stage.

The intended new logical path is:

```text
NV12 frame -> preprocess/resize/convert -> RKNN input
```

instead of:

```text
JPEG bytes -> decode -> RGB image -> preprocess -> RKNN input
```

## 12. UI Design for This Phase

The UI preview path is intentionally unchanged in this version.

That means:

- `health-ui` continues to consume the current preview transport
- `VideoPreviewConsumer` remains as-is
- `VideoPreviewWidget` remains as-is
- no shared-buffer or DMABUF work is included in this document

This scope choice is intentional because the current priority is to fix the analytics-side design error without destabilizing an already working preview path.

## 13. Stability Strategy

The analysis path must be isolated from preview and recording.

Required stability rules:

- preview failure must not imply analysis failure
- analysis failure must not stop preview
- recording must not depend on analysis health
- analysis reconnect must be supported without restarting the camera
- no restart of the preview path is required merely because analysis reconnects

This isolation is one of the main product-quality benefits of the redesign.
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

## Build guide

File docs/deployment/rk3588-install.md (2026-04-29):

# RK3588 Bundle Deployment Guide

## Standard Workflow

This project now uses a fixed deployment workflow:

- cross-build on the Ubuntu host
- assemble `rk3588_bundle/`
- transfer the whole bundle directory to the RK3588 board
- edit `config/runtime_config.json`, or launch `./scripts/config.sh`
- start it on the board with `./scripts/start.sh` or `./scripts/start_all.sh`

The verified SDK path used by the current repository is:

- `/home/elf/aarch64-buildroot-linux-gnu_sdk-buildroot`

The toolchain file provided by this repository is:

- `rk_health_station/cmake/toolchains/rk3588-buildroot-aarch64.cmake`

## 1. Build the Bundle on the Host

Run:

```bash
bash rk_health_station/deploy/scripts/build_rk3588_bundle.sh
```

Default output:

- `rk_health_station/out/rk3588_bundle/`

The bundle contains:

- `bin/healthd`
- `bin/health-ui`
- `bin/health-config-ui`
- `lib/`
- `plugins/`
- `config/runtime_config.json`
- `scripts/config.sh`
- `scripts/start.sh`
- `scripts/stop.sh`
- `scripts/status.sh`

## 2. Verify That the Bundle Is Really ARM64

```bash
file rk_health_station/out/rk3588_bundle/bin/healthd
file rk_health_station/out/rk3588_bundle/bin/health-ui
```

Expected result:

- output contains `ARM aarch64`
- output must not be `x86-64`

## 3. Transfer the Bundle to the Board

Recommended `rsync` method:

```bash
rsync -av rk_health_station/out/rk3588_bundle/ <rk_user>@<rk_ip>:/home/<rk_user>/rk3588_bundle/
```

Equivalent `scp` method:

```bash
scp -r rk_health_station/out/rk3588_bundle <rk_user>@<rk_ip>:/home/<rk_user>/
```

## 4. Start on the Board

```bash
ssh <rk_user>@<rk_ip> '
  cd /home/<rk_user>/rk3588_bundle &&
  chmod +x scripts/*.sh &&
  ./scripts/config.sh &&
  ./scripts/start.sh
'
```

Backend-only start:

```bash
ssh <rk_user>@<rk_ip> '
  cd /home/<rk_user>/rk3588_bundle &&
  ./scripts/start.sh --backend-only
'
```

Advanced one-shot override example:

```bash
ssh <rk_user>@<rk_ip> '
  cd /home/<rk_user>/rk3588_bundle &&
  RK_VIDEO_ANALYSIS_TRANSPORT=dmabuf ./scripts/start.sh --backend-only
'
```

## 5. Status and Stop on the Board

Status:

```bash
ssh <rk_user>@<rk_ip> '
  cd /home/<rk_user>/rk3588_bundle &&
  ./scripts/status.sh
'
```

Stop:

```bash
ssh <rk_user>@<rk_ip> '
  cd /home/<rk_user>/rk3588_bundle &&
  ./scripts/stop.sh
'
```

## 6. Runtime Notes

- logs are written into `rk3588_bundle/logs/`
- pid files are written into `rk3588_bundle/run/`
- database is written into `rk3588_bundle/data/healthd.sqlite`
- local IPC socket defaults to `rk3588_bundle/run/rk_health_station.sock`
- runtime JSON defaults live in `rk3588_bundle/config/runtime_config.json`
- bundle start does not depend on systemd
- if UI cannot open, first inspect `logs/health-ui.log`

## Video Monitor Runtime

- `health-videod` is the only process allowed to open `/dev/video11`
- default video storage directory: `/home/elf/videosurv/`
- UI may change the storage directory through the Video page, but the daemon validates it before applying
- bundle runtime exports `RK_VIDEO_SOCKET_NAME` for the video IPC socket
- current preview transport is local `TCP + MJPEG`
- current preview URL shape is `tcp://127.0.0.1:5602?transport=tcp_mjpeg&boundary=rkpreview`
- `health-ui` consumes preview frames through `QTcpSocket`; it does not open `/dev/video11`
- for architecture details, see `rk_health_station/docs/architecture/camera-video-readme.md`

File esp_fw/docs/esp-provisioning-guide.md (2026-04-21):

# ESP Provisioning Guide

## Preconditions

- ESP32-S3 board is powered and flashed with the `esp_fw` firmware
- RK3588 `healthd` service is reachable on the target network
- You know the Wi-Fi credentials and RK3588 TCP address

## Step 1: Join the provisioning AP

When the ESP has no valid config, it enters provisioning mode automatically.

- SSID: `RKHealth-XXXX`
- password: `rkhealth01`
- portal: `http://192.168.4.1/`

The LEDs indicate provisioning mode with the provisioning blink pattern.

## Step 2: Fill the form

The page refreshes the nearby Wi-Fi list automatically every 3 seconds. Pick one SSID from the dropdown, then enter:

- `wifi_ssid`
- `wifi_password`
- `server_ip` (RK3588 host IP)
- `server_port` (normally `19001`)
- `device_id`
- `device_name`
- `device_secret`

## Step 3: Save and wait for reboot

After submission:

- the firmware writes the config to NVS
- the web page returns `saved, restarting`
- the device reboots automatically into STA mode

## Step 4: Verify bring-up

Use serial logs to verify the sequence:

1. Wi-Fi connected
2. TCP target configured
3. auth result is `ok`, `registration_required`, or `rejected`
4. telemetry starts if auth becomes active
5. while waiting in provisioning mode, a heartbeat log appears every 3 seconds with AP client count and the latest scan summary

Recommended command:

```bash
cd esp_fw
bash tools/serial_capture.sh /dev/ttyACM0 /tmp/esp_fw-session.log
```

If your USB adapter enumerates as `/dev/ttyUSB0`, replace the port accordingly. If `idf.py monitor` reports that the path is "not readable", the usual cause is Linux serial-device permissions rather than firmware logic: check `ls -l /dev/ttyUSB0`, confirm your user is in the `dialout` group, then re-login.

## Expected auth outcomes

- `ok`: device can stream telemetry immediately
- `registration_required`: device is pending approval on RK3588; keep it powered and re-check after approval
- `rejected`: provisioning secret or registration state is wrong; re-provision or reset backend state

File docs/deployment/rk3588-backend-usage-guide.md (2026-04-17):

# RK3588 后端 Bundle 使用说明

## 1. 文档目标

本文档只针对当前仓库 `rk_health_station`、当前 RK3588 开发板，以及当前目录下文档规定的标准作业方式。

本文档的主流程已经统一为：

- 宿主机 `Ubuntu 22.04` 上交叉编译
- 生成可直接交付的 `rk3588_bundle/`
- 通过 `scp` / `rsync` / `ssh` 把 bundle 传到 RK3588
- 在 RK3588 上进入 bundle 目录后执行 `./scripts/start.sh`

这套流程不依赖板端原生编译，也不要求先走 systemd 安装。

---

## 2. 标准来源

本次流程以以下两份本地文档为准：

- `QT编程.txt`
- `RK3588_Qt_AI标准作业手册.md`

直接相关的强制结论是：

1. 正确模式是“宿主机开发 + PC 端交叉编译 + 开发板运行验证”
2. 交叉编译必须使用 RK3588 对应 SDK / 工具链
3. 不能只看构建是否成功，必须再用 `file` 检查产物架构
4. `ssh` / `scp` / `rsync` 的主要用途是传输产物与板端验证

---

## 3. 当前项目的运行结构

当前 RK3588 主站采用双进程 Qt/C++ 架构：

- `healthd`
  - 监听设备 TCP 连接
  - 执行设备认证握手
  - 写入 SQLite
  - 提供本地 IPC
  - 生成告警快照与历史查询数据
- `health-ui`
  - 只连接本地 IPC
  - 不直接连接 ESP32
  - 展示设备、审批、告警、历史等界面

核心代码入口：

- `rk_health_station/rk_app/src/healthd/main.cpp`
- `rk_health_station/rk_app/src/healthd/app/daemon_app.cpp`
- `rk_health_station/rk_app/src/shared/storage/database.cpp`
- `rk_health_station/rk_app/src/healthd/ipc_server/ui_gateway.cpp`

---

## 4. 当前交叉环境基线

当前仓库使用如下交叉环境基线：

- SDK 根目录：`/home/elf/aarch64-buildroot-linux-gnu_sdk-buildroot`
- 交叉 C 编译器：`/home/elf/aarch64-buildroot-linux-gnu_sdk-buildroot/bin/aarch64-buildroot-linux-gnu-gcc`
- 交叉 C++ 编译器：`/home/elf/aarch64-buildroot-linux-gnu_sdk-buildroot/bin/aarch64-buildroot-linux-gnu-g++`
- SDK 自带 `qmake`：`/home/elf/aarch64-buildroot-linux-gnu_sdk-buildroot/bin/qmake`
- sysroot：`/home/elf/aarch64-buildroot-linux-gnu_sdk-buildroot/aarch64-buildroot-linux-gnu/sysroot`
- 工具链文件：`rk_health_station/cmake/toolchains/rk3588-buildroot-aarch64.cmake`

虽然 `rk_health_station` 当前是 CMake 工程，但这套 SDK 中已经包含 Qt5 的 CMake package config，因此可以直接用于当前项目的交叉编译。

---

## 5. 一键交叉编译脚本

当前仓库已提供宿主机一键脚本：

- `rk_health_station/deploy/scripts/build_rk3588_bundle.sh`

执行：

```bash
bash rk_health_station/deploy/scripts/build_rk3588_bundle.sh
```

默认输出：

- `rk_health_station/out/rk3588_bundle/`

该脚本完成的动作：

1. 调用当前仓库工具链文件进行 CMake 交叉配置
2. 交叉编译 `healthd` 和 `health-ui`
3. 用 `file` 验证二进制必须为 `ARM aarch64`
4. 组装 bundle 目录
5. 复制 bundle 运行脚本
6. 复制 Qt 运行库和插件到 bundle 内部

---

## 6. Bundle 目录结构

默认生成结果如下：

- `rk_health_station/out/rk3588_bundle/bin/healthd`
- `rk_health_station/out/rk3588_bundle/bin/health-ui`
- `rk_health_station/out/rk3588_bundle/lib/`
- `rk_health_station/out/rk3588_bundle/plugins/`
- `rk_health_station/out/rk3588_bundle/scripts/start.sh`
- `rk_health_station/out/rk3588_bundle/scripts/stop.sh`
- `rk_health_station/out/rk3588_bundle/scripts/status.sh`
- `rk_health_station/out/rk3588_bundle/logs/`
- `rk_health_station/out/rk3588_bundle/run/`
- `rk_health_station/out/rk3588_bundle/data/`

其中：

- `logs/` 用于保存运行日志
- `run/` 用于保存 pid 和本地 IPC socket
- `data/` 用于保存 SQLite 数据库

---

## 7. 如何验证交叉编译产物正确

执行：

```bash
file rk_health_station/out/rk3588_bundle/bin/healthd
file rk_health_station/out/rk3588_bundle/bin/health-ui
```

只有当输出包含 `ARM aarch64` 时，才允许说“RK3588 交叉编译成功”。

如果输出是 `x86-64`，说明误用了宿主机编译链，不是正确产物。

---

## 8. 如何通过 SSH 传输到板端

### 8.1 推荐用 rsync

```bash
rsync -av rk_health_station/out/rk3588_bundle/ <rk_user>@<rk_ip>:/home/<rk_user>/rk3588_bundle/
```

这条命令的特点是：

- 传的是整个 bundle 目录
- 多次迭代更新时速度更快
- 板端目录结构会和宿主机保持一致

### 8.2 也可以用 scp

```bash
scp -r rk_health_station/out/rk3588_bundle <rk_user>@<rk_ip>:/home/<rk_user>/
```

如果使用这条命令，板端目录通常会是：

- `/home/<rk_user>/rk3588_bundle`

### 8.3 传输后建议检查

```bash
ssh <rk_user>@<rk_ip> '
  ls -l /home/<rk_user>/rk3588_bundle/bin &&
  ls -l /home/<rk_user>/rk3588_bundle/scripts
'
```

---

## 9. 板端如何一键开始运行

进入板端 bundle 目录后执行：

```bash
ssh <rk_user>@<rk_ip> '
  cd /home/<rk_user>/rk3588_bundle &&
  chmod +x scripts/*.sh &&
  ./scripts/start.sh
'
```

如果你只想先启动后端，不启动 UI：

```bash
ssh <rk_user>@<rk_ip> '
  cd /home/<rk_user>/rk3588_bundle &&
  ./scripts/start.sh --backend-only
'
```

### 9.1 `start.sh` 的默认行为

`start.sh` 会：

1. 创建 `logs/`、`run/`、`data/`
2. 设置 `HEALTHD_DB_PATH`
3. 设置 `RK_HEALTH_STATION_SOCKET_NAME`
4. 设置 `LD_LIBRARY_PATH`
5. 设置 `QT_PLUGIN_PATH`
6. 启动 `healthd`
7. 等待本地 socket 就绪
8. 再启动 `health-ui`

### 9.2 日志位置

- 后端日志：`logs/healthd.log`
- UI 日志：`logs/health-ui.log`

### 9.3 运行状态查看

```bash
ssh <rk_user>@<rk_ip> '
  cd /home/<rk_user>/rk3588_bundle &&
  ./scripts/status.sh
'
```

### 9.4 停止运行

```bash
ssh <rk_user>@<rk_ip> '
  cd /home/<rk_user>/rk3588_bundle &&
  ./scripts/stop.sh
'
```

---

## 10. 运行时目录说明

bundle 运行时默认使用以下路径：

- 数据库：`data/healthd.sqlite`
- 本地 IPC socket：`run/rk_health_station.sock`
- 后端 pid：`run/healthd.pid`
- UI pid：`run/health-ui.pid`
- 后端日志：`logs/healthd.log`
- UI 日志：`logs/health-ui.log`

这意味着整个 bundle 目录天然自包含，便于移动、打包和替换。

---

## 11. 如果 UI 无法正常打开

优先检查：

1. `logs/health-ui.log`
2. 板端当前图形会话是否可用
3. `DISPLAY` / `WAYLAND_DISPLAY` / `QT_QPA_PLATFORM`
4. 板端对 bundle 中 Qt 运行库的兼容情况

如果只是先验证后端功能，可以先用：

```bash
./scripts/start.sh --backend-only
```

---

## 12. 与 systemd 安装流的关系

当前仓库仍然保留：

- `deploy/scripts/install.sh`
- `deploy/scripts/start.sh`
- `deploy/scripts/stop.sh`
- `deploy/systemd/*.service`

但这些现在属于可选的 systemd 安装流。

你当前要求的主流程，已经改成：

- 一键交叉编译 bundle
- 传输 bundle 到板端
- 直接执行 `./scripts/start.sh`

---

## 13. 当前仍需注意的后端已知问题

这次新增的是 bundle 部署能力，不改变之前后端代码审查结论。当前仍需注意：

- `health-ui.service` 目前按 root 系统服务部署，Ubuntu 图形会话下可能导致 UI 不显示
- 历史分钟聚合当前未覆盖 `acceleration`
- 告警接口当前更接近实时快照，不是完整持久化告警历史
- `device_pending_requests` 建表逻辑有重复

## Video Monitor Runtime

- `health-videod` is the only process allowed to open `/dev/video11`
- default video storage directory: `/home/elf/videosurv/`
- UI may change the storage directory through the Video page, but the daemon validates it before applying
- bundle runtime exports `RK_VIDEO_SOCKET_NAME` for the video IPC socket
- current preview transport is local `TCP + MJPEG`
- current preview URL shape is `tcp://127.0.0.1:5602?transport=tcp_mjpeg&boundary=rkpreview`
- `health-ui` consumes preview frames through `QTcpSocket`; it does not open `/dev/video11`
- for architecture details, see `rk_health_station/docs/architecture/camera-video-readme.md`

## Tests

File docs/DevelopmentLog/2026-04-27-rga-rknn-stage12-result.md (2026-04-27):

# 2026-04-27 RGA + RKNN Stage 1/2 Result

## Scope

Implemented Scheme B in a bounded form:

- `health-videod` publishes model-sized RGB analysis frames with pose letterbox metadata.
- The shared descriptor and shared-memory ring preserve `posePreprocessed`, `poseXPad`, `poseYPad`, and `poseScale`.
- `health-falld` consumes model-ready RGB frames without re-letterboxing and uses the supplied metadata for pose post-processing.
- RKNN pose inference preallocates output buffers by default (`output_prealloc_path=true`).
- A full RKNN IO-memory path remains available for probes with `RK_FALL_RKNN_IO_MEM=zero_copy`, but it is not the default because it did not improve total timing on this board.

## Board Comparison

Board: `elf@192.168.137.179`  
Runtime: `/home/elf/rk3588_bundle`, `DISPLAY=:1`, `RK_RUNTIME_MODE=system`  
Baseline commit: `d50eed2fd9989397a4baaee95d1dcefdf5cc3e01` (`main`)

| Metric, last 200 pose samples | Fresh main baseline | Scheme B final | Delta |
| --- | ---: | ---: | ---: |
| `preprocess_ms avg` | 0.000 | 0.000 | 0.000 |
| `inputs_set_ms avg` | 0.000 | 0.000 | 0.000 |
| `rknn_run_ms avg` | 21.705 | 21.540 | -0.165 ms |
| `outputs_get_ms avg` | 1.000 | 1.000 | 0.000 ms |
| `post_process_ms avg` | 0.000 | 0.000 | 0.000 |
| `total_ms avg` | 23.885 | 23.675 | -0.210 ms (-0.9%) |
| timing rows | 935 | 936 | comparable |
| `output_prealloc_path` | unavailable | 200 / 200 | enabled |

Process snapshot after about 60 seconds:

| Process metric | Fresh main baseline | Scheme B final |
| --- | ---: | ---: |
| `health-videod %CPU` | 2.5 | 2.8 |
| `health-falld %CPU` | 7.6 | 7.6 |
| `health-ui %CPU` | 0.2 | 0.3 |

Functional status stayed healthy in both runs: all four services running, health socket present, video socket present, analysis socket present, and fall socket present. Both runs sustained `15.0 ingest_fps` and `15.0 infer_fps`.

## Probe Notes

- Full RKNN IO memory (`RK_FALL_RKNN_IO_MEM=zero_copy`) was tested separately. It made `io_mem_path=true` and reduced `outputs_get_ms` to `0.0`, but shifted time into `rknn_run_ms`; total timing was effectively neutral around `23.77 ms`, so it is kept opt-in.
- Querying native NHWC output attributes for full IO memory caused a severe post-processing regression on this model/board combination, so that probe was reverted.
- The current main baseline already had `preprocess_ms=0`, so Stage 1 cannot produce a large pose-side gain until Stage 3 removes the remaining cross-process payload copy with DMABUF/fd transport.

## Conclusion

Scheme B final shows a small but measurable pose timing improvement versus a fresh `main` baseline on the same board run: `total_ms` improved by about `0.21 ms` (`0.9%`) while preserving 15 FPS ingestion/inference. The change is safe to carry forward, but the larger expected performance win should come from Stage 3 DMABUF/fd transport.

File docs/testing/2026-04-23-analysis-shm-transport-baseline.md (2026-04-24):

# Analysis SHM Transport Baseline

Date: 2026-04-24

- Baseline branch: `main`
- Baseline commit: `45cd021`
- Candidate branch: `feature/analysis-shm-transport`
- Candidate commit: `e9c6c6b`
- Hardware: `RK3588 board @ 192.168.137.179` (`elf2-desktop`)
- Video: `/home/elf/Videos/video.mp4`

## Commands

Build baseline bundle from the main checkout:

```bash
cd /home/elf/workspace/QTtest/Qt例程源码/rk_health_station
BUILD_DIR=/tmp/rk_health_station-build-rk3588-main-shm-baseline \
BUNDLE_DIR=$PWD/out/rk3588_bundle_analysis_shm_main \
bash deploy/scripts/build_rk3588_bundle.sh
```

Build candidate bundle from the worktree:

```bash
cd /home/elf/workspace/QTtest/Qt例程源码/rk_health_station/.worktrees/feature-analysis-shm-transport
BUILD_DIR=/tmp/rk_health_station-build-rk3588-candidate-shm \
BUNDLE_DIR=$PWD/out/rk3588_bundle_analysis_shm_candidate \
bash deploy/scripts/build_rk3588_bundle.sh
```

Sync bundles in place on the board to avoid the nearly-full root filesystem:

```bash
rsync -az --inplace --delete out/rk3588_bundle_analysis_shm_main/ \
  elf@192.168.137.179:/home/elf/rk3588_bundle_main_test/

rsync -az --inplace --delete out/rk3588_bundle_analysis_shm_candidate/ \
  elf@192.168.137.179:/home/elf/rk3588_bundle_candidate/
```

Run the latency harness:

```bash
python3 deploy/tests/measure_rk3588_test_mode_latency.py \
  --host elf@192.168.137.179 \
  --password elf \
  --bundle-dir /home/elf/rk3588_bundle_main_test \
  --video-file /home/elf/Videos/video.mp4

python3 deploy/tests/measure_rk3588_test_mode_latency.py \
  --host elf@192.168.137.179 \
  --password elf \
  --bundle-dir /home/elf/rk3588_bundle_candidate \
  --video-file /home/elf/Videos/video.mp4
```

## Raw Metrics

### Main baseline

```json
{
  "analysis_ingest_ts_ms": null,
  "analysis_ingress_latency_ms": -73,
  "analysis_publish_ts_ms": null,
  "classification_stage_latency_ms": 1382,
  "consumer_cpu_pct": 27.2,
  "first_classification_ts_ms": 1776961552597,
  "first_frame_ts_ms": 1776961551215,
  "first_state": "stand",
  "playback_start_ts_ms": 1776961551288,
  "producer_cpu_pct": 7.2,
  "producer_dropped_frames": 0,
  "startup_classification_latency_ms": 1309,
  "transport_latency_ms": null
}
```

### SHM candidate

```json
{
  "analysis_ingest_ts_ms": 1776961482812,
  "analysis_ingress_latency_ms": -81,
  "analysis_publish_ts_ms": 1776961481941,
  "classification_stage_latency_ms": 1342,
  "consumer_cpu_pct": 25.2,
  "first_classification_ts_ms": 1776961484154,
  "first_frame_ts_ms": 1776961482812,
  "first_state": "stand",
  "playback_start_ts_ms": 1776961482893,
  "producer_cpu_pct": 6.2,
  "producer_dropped_frames": 0,
  "startup_classification_latency_ms": 1261,
  "transport_latency_ms": 871
}
```

## Comparison

- Startup classification latency: `1261 ms` vs `1309 ms` (`-48 ms`, candidate faster)
- Classification stage latency: `1342 ms` vs `1382 ms` (`-40 ms`, candidate faster)
- Producer CPU: `6.2%` vs `7.2%` (`-1.0%`, candidate lower)
- Consumer CPU: `25.2%` vs `27.2%` (`-2.0%`, candidate lower)
- Dropped frames: `0` vs `0`

## Notes

- The first SHM implementation regressed badly on board because two effects compounded:
  - the producer ring used only `4` slots, which let startup bursts overwrite unread slots;
  - `AnalysisStreamClient` still collapsed each descriptor burst into a single `frameReceived(...)`, which throttled the effective frame rate after switching from large socket payloads to tiny descriptors.
- The final candidate fixes both issues by:
  - increasing the production ring size to `32` slots;
  - emitting every successfully reconstructed frame to the fall pipeline instead of only the last frame from a ready-read burst.
- `transport_latency_ms` is only available on the SHM candidate because `main` still uses the old full-payload socket transport. The current marker placement can also include a small amount of pre-playback warmup traffic, so the board-level pass/fail decision should use `startup_classification_latency_ms` and CPU deltas rather than the raw transport field alone.

## Conclusion

The shared-memory transport is better than the current `main` baseline on the measured board run:

- it improves startup classification latency by `48 ms`;
- it reduces producer CPU by `1.0%`;
- it reduces consumer CPU by `2.0%`;
- it does so without introducing producer-side dropped frames in the measured run.

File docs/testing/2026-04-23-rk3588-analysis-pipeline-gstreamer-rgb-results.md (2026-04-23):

# RK3588 Analysis Pipeline GStreamer RGB Validation Results

Date: 2026-04-23

## Scope

This validation checks the approved analysis-pipeline change:

- UI preview path stays on the existing MJPEG branch.
- `health-videod` emits fixed-size RGB analysis frames for `health-falld`.
- `health-falld` uses the RGB fast path and avoids the old NV12 CPU preprocessing in the production path.

## Host Verification

Focused host tests passed in `out/build-rk_app-host-tests`:

- `analysis_stream_protocol_test`
- `analysis_output_backend_test`
- `video_service_analysis_test`
- `gstreamer_video_pipeline_backend_test`
- `analysis_stream_client_test`
- `fall_runtime_pose_stub_test`
- `nv12_preprocessor_test`
- `rgb_pose_fast_path_test`
- `pose_stage_timing_logger_test`

Command used:

```bash
ctest --test-dir out/build-rk_app-host-tests -R \
  'analysis_stream_protocol_test|analysis_output_backend_test|video_service_analysis_test|gstreamer_video_pipeline_backend_test|analysis_stream_client_test|fall_runtime_pose_stub_test|nv12_preprocessor_test|rgb_pose_fast_path_test|pose_stage_timing_logger_test' \
  --output-on-failure
```

## RK3588 Build + Deploy

Bundle build:

```bash
BUILD_DIR=/tmp/rk_health_station-build-rk3588-featureopt \
BUNDLE_DIR=out/rk3588_bundle_latency_candidate \
bash deploy/scripts/build_rk3588_bundle.sh
```

Board deploy:

```bash
rsync -az --inplace --delete out/rk3588_bundle_latency_candidate/ \
  elf@192.168.137.179:/home/elf/rk3588_bundle_candidate/
```

## Board Validation Notes

The board root filesystem was full during validation, so the normal `start.sh` path could fail when creating pid/log files under `/home/elf/rk3588_bundle_candidate`.

To avoid that environmental false negative, the final A/B measurement used the same deployed binaries but started the services with sockets, sqlite DB, latency markers, and pose-stage traces placed under `/dev/shm`.

That workaround does not change the binaries under test; it only avoids filesystem exhaustion on the target.

Follow-up verification after disk space recovery:

- the normal bundle startup path `./scripts/start.sh --backend-only` was re-validated successfully
- `healthd`, `health-videod`, and `health-falld` all started normally
- the standard latency harness also ran successfully against the normal bundle startup flow

## A/B Latency Result

Test input:

- file: `/home/elf/Videos/video.mp4`
- success criterion for this milestone: candidate startup classification latency must be no worse than `main`

### Current `main` bundle

- bundle: `/home/elf/rk3588_bundle_main`
- result:
  - `startup_classification_latency_ms`: `2160`
  - `classification_stage_latency_ms`: `2153`
  - `analysis_ingress_latency_ms`: `7`
  - `first_state`: `stand`

### Candidate RGB pipeline bundle

- bundle: `/home/elf/rk3588_bundle_candidate`
- result:
  - `startup_classification_latency_ms`: `1315`
  - `classification_stage_latency_ms`: `1399`
  - `analysis_ingress_latency_ms`: `-84`
  - `first_state`: `stand`

### Candidate RGB pipeline bundle (normal `start.sh` flow after freeing disk space)

- bundle: `/home/elf/rk3588_bundle_candidate`
- result:
  - `startup_classification_latency_ms`: `1259`
  - `classification_stage_latency_ms`: `1362`
  - `analysis_ingress_latency_ms`: `-103`
  - `first_state`: `stand`

### Comparison

- Candidate beats deployed `main` by `845 ms` on startup classification latency (`2160 -> 1315 ms`).
- The remaining latency is now dominated by model/inference/classification stages rather than frame preprocessing.

## Pose Stage Timing Result

Candidate pose-stage trace summary from the same board run:

- `pixel_format`: `rgb`
- `width`: `640`
- `height`: `640`
- `samples`: `46`
- `avg_preprocess_ms`: `0.0`
- `avg_rknn_run_ms`: `24.93`
- `avg_total_ms`: `27.65`

Interpretation:

- The previous regression source (`health-falld` CPU-side preprocessing) is removed from the hot path.
- `health-falld` is now receiving the model-shaped RGB frames expected by the fast path.

## Conclusion

This change meets the current milestone:

- the new candidate is **not worse than `main`**
- the candidate is materially faster than `main` on first classification
- the pose preprocessing stage is effectively eliminated in the production path on board

The stricter future target of `<= 300 ms` from video-time event to classification is still not met; that requires a separate optimization round focused on the remaining inference/classification budget rather than image-format conversion.

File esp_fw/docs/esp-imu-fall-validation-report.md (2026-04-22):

# ESP IMU Fall Validation Report

## Validation matrix

- Firmware build: `idf.py build`
- Host parse tests: `ctest --test-dir out/build-rk_app-host -R 'shared_models_contract_test|healthd_tcp_smoke_test' --output-on-failure`
- Model artifact present: `esp_fw/models/imu_fall_waist_3class.espdl`
- External offline workspace: `/home/elf/workspace/imu_fall_detect/imu_fall_model`
- Board flash: `idf.py -p /dev/ttyACM0 flash monitor`
- Expected runtime logs:
  - `FALL_CLS: model_addr=0x........ aligned16=1`
  - `FALL_CLS: largest_internal_kb=... largest_psram_kb=...`
  - `FALL_CLS: esp-dl model loaded successfully`
  - `imu_fall class=<0|1|2> probs=[...]`

## Runtime notes

- The first implementation targets waist-mounted SisFall-enhanced windows only.
- The ESP side keeps all three class probabilities and does not collapse them to a binary fall label.
- The RK3588 `healthd` side parses the extra IMU fields for future fusion logic.

## Offline model snapshot

- Training command: `python3 -u /home/elf/workspace/imu_fall_detect/imu_fall_model/train.py --dataset /home/elf/workspace/imu_fall_detect/sisfall-enhanced --output-dir /tmp/imu_fall_train_final --epochs 8 --batch-size 512`
- Best validation loss observed: `0.2147`
- Test-set report from `evaluate.py`:
  - `non_fall`: precision `0.9916`, recall `0.9746`
  - `pre_impact`: precision `0.1033`, recall `0.2166`
  - `fall`: precision `0.7289`, recall `0.9141`
  - macro F1: `0.6447`
- Export + quantization path:
  - `python3 /home/elf/workspace/imu_fall_detect/imu_fall_model/export_onnx.py --checkpoint /tmp/imu_fall_train_final/fallnet_waist_3class.pt --output /tmp/imu_fall_train_final/fallnet_waist_3class.onnx`
  - `python3 /home/elf/workspace/imu_fall_detect/imu_fall_model/quantize_espdl.py --onnx /tmp/imu_fall_train_final/fallnet_waist_3class.onnx --output /home/elf/workspace/imu_fall_detect/artifacts/imu_fall_waist_3class.espdl --calibration-dir /home/elf/workspace/imu_fall_detect/sisfall-enhanced --max-samples 64 --batch-size 8`
  - `bash esp_fw/tools/run_imu_model_pipeline.sh`
- Embedded artifact size: about `15 KB`

## Runtime repair notes

- The original reboot loop was caused by two conditions at the same time:
  - the embedded `.espdl` blob was not guaranteed to be 16-byte aligned
  - PSRAM was disabled, so `esp-dl` exhausted available allocatable memory during model load
- The repaired runtime now depends on:
  - aligned model embedding via `target_add_aligned_binary_data(...)`
  - PSRAM enabled in `sdkconfig.defaults`
  - explicit serial diagnostics for model size, flash address alignment, and largest free internal/PSRAM blocks

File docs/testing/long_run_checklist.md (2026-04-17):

# Long Run Checklist

## Connectivity

- multiple ESP32 devices can stay connected to one RK3588 at the same time
- approved devices reconnect automatically after WiFi interruption
- pending devices remain pending until manually approved
- rejected or disabled devices cannot push authenticated telemetry

## Process Stability

- `healthd` auto-restarts after forced kill
- `health-ui` auto-restarts after forced kill
- restarting `health-ui` does not break `healthd`
- restarting `healthd` lets `health-ui` recover cleanly after backend returns

## Storage

- `/var/lib/rk_health_station/healthd.sqlite` is created and keeps device metadata
- telemetry samples continue to append during long run
- minute aggregation rows continue to update over time
- device approval / rename / enable-disable / secret reset leave audit records

## UI Behavior

- dashboard shows current primary device data
- alerts page updates with low HR / high HR / low SpO2 / low battery conditions
- history page can query minute series for at least one device
- device approval and settings pages still work after long run

## Video Monitor Checks

- run `rk_health_station/deploy/tests/video_preview_probe.sh` on the target board
- confirm the selected preview transport still passes on the current image
- verify preview appears in `health-ui`
- verify snapshot and recording still work after preview starts

## Resource / Service Health

- 24h run without obvious memory growth in `healthd`
- 24h run without obvious memory growth in `health-ui`
- TCP port `19001` remains bound by `healthd`
- local IPC socket remains reachable by `health-ui`
- journald logs remain readable and rotate normally

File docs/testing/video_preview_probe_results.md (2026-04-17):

# Video Preview Probe Results

> Historical note: this file records an earlier preview transport probe and is no longer the live UI preview design.
> The current production path is `TCP + MJPEG`; see `rk_health_station/docs/architecture/camera-video-readme.md`.

- Board: `elf@192.168.137.179`
- Camera: `front_cam -> /dev/video11`
- Preferred transport: `udp_mpegts_h264`
- Validation date: `2026-04-15`
- Validation command:
  - producer: `gst-launch-1.0 -e v4l2src device=/dev/video11 ! video/x-raw,format=NV12,width=640,height=480,framerate=30/1 ! mpph264enc ! h264parse ! mpegtsmux ! udpsink host=127.0.0.1 port=5602 sync=false async=false`
  - consumer: `gst-launch-1.0 -v udpsrc port=5602 caps='video/mpegts,systemstream=(boolean)true,packetsize=(int)188' ! tsdemux ! h264parse ! mppvideodec ! fakesink sync=false`
- Why chosen:
  - producer and consumer both validate successfully on the RK3588 board
  - the stream can be consumed through a simple local UDP URL without opening `/dev/video11` in the UI process
  - this is closer to what `QMediaPlayer` will need than the raw RTP-only probe

## Supplemental Notes

- `udp_h264` producer-only probe also starts successfully
- `tcp_mjpeg` producer-only probe also starts successfully
- those two probes alone do not prove easy consumer compatibility, so they were not selected as the default preview transport

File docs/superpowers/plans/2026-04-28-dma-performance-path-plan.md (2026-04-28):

# DMA Performance Path Implementation Plan

> **For agentic workers:** REQUIRED SUB-SKILL: Use superpowers:subagent-driven-development (recommended) or superpowers:executing-plans to implement this plan task-by-task. Steps use checkbox (`- [ ]`) syntax for tracking.

**Goal:** Reduce video analysis CPU memory copies by letting RGA write model-ready RGB frames directly into DMA heap buffers and publishing those fds.

**Architecture:** Add an optional DMA-output conversion interface to `AnalysisFrameConverter`, implement it in `RgaFrameConverter`, and have `GstreamerVideoPipelineBackend` use it when `RK_VIDEO_RGA_OUTPUT_DMABUF=1` and the analysis consumer supports DMABUF. Preserve the existing QByteArray path as fallback.

**Tech Stack:** C++17, Qt, RK RGA `im2d`, Linux DMA heap, existing analysis descriptor fd transport, CMake/CTest, RK3588 board validation.

---

### Task 1: Converter DMA Output Contract

**Files:**
- Modify: `rk_app/src/health_videod/analysis/analysis_frame_converter.h`
- Modify: `rk_app/src/tests/video_daemon_tests/gstreamer_video_pipeline_backend_test.cpp`

- [ ] Add a small `AnalysisDmaBuffer` result type with fd, payload bytes, stride, and metadata.
- [ ] Add virtual `convertNv12ToRgbDma(...)` with a default false implementation so host tests and existing fake converters still build.
- [ ] Write a failing test that enables `RK_VIDEO_RGA_OUTPUT_DMABUF=1`, uses a fake converter returning a memfd-backed RGB frame, and asserts the backend publishes a DMABUF descriptor without calling the QByteArray converter.
- [ ] Run `cmake --build out/build-rk_app-host --target gstreamer_video_pipeline_backend_test -j4` and the focused ctest; expected failure: no DMABUF conversion path yet.

### Task 2: Backend DMA Output Path

**Files:**
- Modify: `rk_app/src/health_videod/pipeline/gstreamer_video_pipeline_backend.cpp`
- Modify: `rk_app/src/tests/video_daemon_tests/gstreamer_video_pipeline_backend_test.cpp`

- [ ] Add `RK_VIDEO_RGA_OUTPUT_DMABUF` env parsing.
- [ ] In `processAnalysisFrameBytes`, when analysis backend is RGA, DMABUF output is requested, and the analysis source supports DMABUF, call `convertNv12ToRgbDma` first.
- [ ] Publish the returned fd with descriptor fields: RGB, 640x640, payload bytes, one plane, offset, stride.
- [ ] Close the returned fd after `publishDmaBufDescriptor` because the fd sender duplicates it.
- [ ] Fallback to current QByteArray path if DMA output conversion fails.
- [ ] Run the focused host test; expected pass.

### Task 3: RGA DMA Heap Implementation

**Files:**
- Modify: `rk_app/src/health_videod/analysis/rga_frame_converter.cpp`
- Modify: `rk_app/src/health_videod/analysis/rga_frame_converter.h`

- [ ] Allocate DMA heap output with `/dev/dma_heap/system-uncached-dma32` or `RK_VIDEO_ANALYSIS_DMA_HEAP`.
- [ ] Map/fill the output with 114 padding.
- [ ] Use RGA fd output (`importbuffer_fd` / `wrapbuffer_handle`) and virtual NV12 input for Stage 1.
- [ ] Return fd ownership to the caller on success; close on failure.
- [ ] Keep `convertNv12ToRgb` unchanged for fallback.
- [ ] Cross-build with `BUILD_DIR=/tmp/rk_health_station-build-rk3588-dma-output BUILD_TESTING=OFF bash deploy/scripts/build_rk3588_bundle.sh`.

### Task 4: Board Verification

**Files:**
- No source changes expected.

- [ ] Deploy `out/rk3588_bundle` to `/home/elf/rk3588_bundle`.
- [ ] Run the board with `RK_VIDEO_PIPELINE_BACKEND=inproc_gst`, `RK_VIDEO_ANALYSIS_TRANSPORT=dmabuf`, `RK_VIDEO_RGA_OUTPUT_DMABUF=1`, and `RK_FALL_RKNN_INPUT_DMABUF=1`.
- [ ] Verify `video_runtime` logs show DMA output path enabled or fallback reason.
- [ ] Verify latency markers contain `transport=dmabuf` and fall pose timing contains `input_dmabuf_path=true`.
- [ ] Verify `video_perf` and `fall_perf` remain stable and no `gst-launch-1.0` process is running.

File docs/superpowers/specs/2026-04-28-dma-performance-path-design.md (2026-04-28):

# DMA Performance Path Design

## Goal

Improve RK3588 video analysis performance by reducing full-frame CPU memory copies and moving the analysis input path toward DMABUF-backed buffers.

## Current State

The in-process GStreamer backend can run without an external `gst-launch` process and publishes analysis descriptors over DMABUF transport. However, `health-videod` still maps/copies appsink frames into `QByteArray`, RGA writes RGB output into `QByteArray`, then `health-videod` copies that RGB payload into a newly allocated DMA heap buffer before publishing the fd to `health-falld`.

## Recommended Architecture

Use a staged DMA path. First, keep appsink input handling unchanged but make RGA write RGB 640x640 output directly into a DMA heap buffer, then publish that fd. This removes the most certain large copy while preserving the existing `health-falld`/RKNN RGB DMABUF fast path. Second, probe and optionally use GstBuffer DMABUF memory as RGA input when the board pipeline exposes it.

## Data Flow

Stage 1 target:

```text
appsink NV12 bytes -> RGA virtual input -> RGA DMA heap RGB output -> descriptor fd -> health-falld -> RKNN fd input
```

Stage 2 target:

```text
appsink GstBuffer DMABUF NV12 -> RGA fd input -> RGA DMA heap RGB output -> descriptor fd -> health-falld -> RKNN fd input
```

## Runtime Controls

- Keep existing default/fallback behavior intact.
- Add `RK_VIDEO_RGA_OUTPUT_DMABUF=1` to enable RGA DMA output.
- Add a later `RK_VIDEO_GST_DMABUF_INPUT=1` or equivalent for GstBuffer DMABUF input after Stage 1 is stable.
- On any DMA/RGA fd failure, fall back to the current `QByteArray` path and log the reason.

## Verification

Each stage must be host-tested where possible, cross-built, deployed to the RK3588 board, and run with:

```bash
RK_VIDEO_PIPELINE_BACKEND=inproc_gst
RK_VIDEO_ANALYSIS_TRANSPORT=dmabuf
RK_VIDEO_RGA_OUTPUT_DMABUF=1
RK_FALL_RKNN_INPUT_DMABUF=1
```

Success requires stable service startup, no external `gst-launch-1.0` process, `transport=dmabuf`, `input_dmabuf_path=true`, and video/fall performance logs with no fatal pipeline errors.

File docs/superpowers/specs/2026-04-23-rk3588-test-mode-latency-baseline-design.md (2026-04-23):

## RK3588 Test-Mode Latency Baseline Design

Date: 2026-04-23
Status: Approved for planning

## 1. Goal

Establish a reliable board-level latency baseline for fall-analysis startup in test mode, using `main` as the reference implementation and the current worktree as the candidate implementation.

This design does not attempt to solve the latency problem directly. Its immediate goal is to measure the gap precisely enough that the next implementation phase can target the right bottleneck.

## 2. User-Approved Scope

The user explicitly approved the following scope:

- use current `main` as the old-engineering baseline
- use the current worktree as the new implementation under test
- run both on the same RK3588 board
- use the same test input file: `~/Videos/video.mp4`
- use the existing test-mode path, not a separate ad hoc harness
- define the timing start as the moment `health-videod` successfully enters `test_file` playback
- define the timing end as the first emitted classification result such as `monitoring` / `stand` / similar first-state output after a person is present
- first-stage optimization goal: make the current worktree "not worse than main"

The user also clarified an important business constraint:

- the video begins with a person already visible, so startup-classification latency is the primary metric

## 3. Problem Statement

The current worktree is subjectively much slower than `main` during test-mode playback, even after the recent NV12 analysis-path optimization and lag/backlog fixes.

At this point, directly proposing more code changes would be premature because the observed regression may come from multiple different layers:

- delayed start of the test-file playback path in `health-videod`
- slower first analysis-frame delivery from `health-videod` to `health-falld`
- slower startup classification behavior inside `health-falld`
- different frame dropping or startup buffering behavior between `main` and the current worktree
- sequence-window or first-result policy differences that were previously masked by the older JPEG-derived path

Because the product complaint is "new engineering feels much slower than old engineering," the correct next step is a strict A/B comparison under the same board conditions.

## 4. Success Metric

### 4.1 Primary metric

For each run, measure:

```text
startup classification latency = first classification timestamp - test playback start timestamp
```

Where:

- `test playback start timestamp` = the moment the board-side video service enters `test_file` playback for `~/Videos/video.mp4`
- `first classification timestamp` = the first classification output generated by `health-falld` for that run, including bootstrap states such as `monitoring`, `stand`, or equivalent first visible-person state

### 4.2 First-stage acceptance rule

The current worktree passes the first-stage goal only if:

```text
startup classification latency(worktree) <= startup classification latency(main)
```

The comparison must be made on the same board and with the same test file and start procedure.

### 4.3 Supporting breakdown metrics

To make root-cause analysis possible, also collect:

```text
analysis ingress latency = first analysis-frame ingress timestamp - test playback start timestamp
classification stage latency = first classification timestamp - first analysis-frame ingress timestamp
```

These supporting metrics make it possible to decide whether the regression is dominated by:

- the video/analysis export side
- the fall-analysis consumer side
- or both

## 5. Test Design

### 5.1 Compared builds

Two builds will be tested:

1. `main`
   - role: baseline
2. current worktree
   - role: candidate

Both must be deployed to the same RK3588 runtime environment one at a time.

### 5.2 Shared runtime conditions

Each run must use the same conditions:

- same RK3588 board
- same camera-independent test mode
- same file: `~/Videos/video.mp4`
- same service startup flow
- same runtime mode (`system`)
- same output sockets and bundle script flow

The board must be cleanly stopped between runs so stale processes or socket state do not contaminate the comparison.

### 5.3 Start and end event definitions

#### Start event

The official start event is the board-observed moment when test playback begins for `~/Videos/video.mp4`.

The implementation phase may realize this using one of the following equivalent signals:

- a `health-videod` log line emitted exactly when `start_test_input` becomes active
- an explicit timestamp recorded by `VideoService` when the test-input state transitions to `test_file`
- another board-local signal that is equally precise and unambiguous

The key requirement is consistency between `main` and the worktree.

#### End event

The official end event is the first classification message emitted by `health-falld` after the run starts.

This includes first-available visible-person states such as:

- `monitoring`
- `stand`
- other equivalent non-empty first classification states

The end event is intentionally not limited to fall-only states, because the user wants the first useful model output after a person appears.

## 6. Recommended Measurement Approach

### Recommended approach: automated board-side A/B latency harness

Use a small, repeatable board-side measurement flow that starts the backend stack, enables test mode with `~/Videos/video.mp4`, captures timestamps for the start event and first classification event, and prints a structured result for each build.

Why this is the recommended approach:

- it compares `main` and the worktree under identical conditions
- it removes subjective timing judgment
- it produces data that can be re-run after each optimization attempt
- it gives enough breakdown detail to locate the regression boundary

### Alternatives considered

#### Manual UI / log observation only

Pros:

- fastest to begin

Cons:

- not precise enough for engineering decisions
- hard to separate playback-start delay from classification-start delay
- not repeatable enough for regression tracking

#### End-to-end total latency only, no stage breakdown

Pros:

- simple metric
- directly matches the first-stage user complaint

Cons:

- if the worktree is slower, it will not tell us where the extra delay is introduced

The stage-breakdown design is therefore preferred.

## 7. Required Instrumentation Principles

Instrumentation added in the next phase must obey these rules:

1. Use the same measurement semantics for `main` and the worktree
2. Avoid changing business behavior just to measure latency
3. Prefer explicit timestamped log or IPC events over indirect inference
4. Keep the measurement path removable or low-risk after debugging
5. Ensure one run cannot reuse old sockets, stale subscribers, or buffered classification output from a previous run

## 8. Likely Outcomes and Interpretation

### Outcome A: worktree is slower before first analysis ingress

Interpretation:

- regression is likely on the `health-videod` side
- examples: test-file startup behavior, analysis branch throttling, initial frame publication policy

### Outcome B: worktree matches analysis ingress but is slower before first classification

Interpretation:

- regression is likely on the `health-falld` side
- examples: first-result policy, sequence warm-up requirement, startup buffering, model invocation strategy

### Outcome C: both stages are slower

Interpretation:

- regression is cross-service
- optimization must be split across producer and consumer boundaries

### Outcome D: worktree is not worse than `main`

Interpretation:

- the subjective lag report may come from a separate perception issue
- examples: UI/result alignment, overlay update cadence, result persistence policy
- in that case the next debugging step should move to presentation synchronization rather than startup classification latency

## 9. Out of Scope

The following are explicitly out of scope for this design document:

- immediately redesigning the action/fall model
- changing sequence length or training strategy before the baseline gap is measured
- redesigning the UI preview path
- switching the UI to shared memory or DMABUF
- claiming a hard `<= 0.3s` target before the `main` baseline is known

Those may become later phases, but they are not part of this baseline-establishment step.

## 10. Planned Next Step

After this spec is approved, the next step is to create an implementation plan that:

- adds a repeatable latency measurement path for `main` and the worktree
- runs both builds on the RK3588 board with `~/Videos/video.mp4`
- records the first-classification startup latency and supporting breakdown metrics
- uses the resulting A/B data to define the minimal code change required to make the worktree not worse than `main`

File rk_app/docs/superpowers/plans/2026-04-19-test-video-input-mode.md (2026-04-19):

# Test Video Input Mode Implementation Plan

> **For agentic workers:** REQUIRED SUB-SKILL: Use superpowers:subagent-driven-development (recommended) or superpowers:executing-plans to implement this plan task-by-task. Steps use checkbox (`- [ ]`) syntax for tracking.

**Goal:** Add a Qt-driven test mode that temporarily switches the video monitor page from live camera input to a user-selected MP4 file, while preserving the existing ByteTrack fall-detection pipeline.

**Architecture:** Keep `health-videod` as the sole owner of video input mode. Extend shared video status/IPC so the UI can request test-mode entry and render backend-owned mode state. Generalize the preview backend to support file input and notify `VideoService` when MP4 playback finishes, while `health-falld` remains unchanged and keeps consuming analysis frames from the existing analysis socket.

**Tech Stack:** C++17, Qt Core/Network/Widgets/Test, existing local video IPC, GStreamer preview pipeline, current RK3588 `health-videod` / `health-falld` architecture.

---

## File Structure

### Existing files to modify

- `rk_app/src/shared/models/video_models.h`
  - Extend `VideoChannelStatus` with backend-owned test-mode fields.
- `rk_app/src/shared/protocol/video_ipc.h`
  - Keep the command/result types unchanged structurally, but expose the richer status payload through serialization helpers.
- `rk_app/src/shared/protocol/video_ipc.cpp`
  - Serialize and parse new status fields.
- `rk_app/src/health_ui/ipc_client/video_ipc_client.h`
  - Extend `AbstractVideoClient` / `VideoIpcClient` with test-mode actions.
- `rk_app/src/health_ui/ipc_client/video_ipc_client.cpp`
  - Send `start_test_input` / `stop_test_input` commands.
- `rk_app/src/health_videod/core/video_service.h`
  - Add test-mode entry/exit APIs and observer hooks for playback-finished events.
- `rk_app/src/health_videod/core/video_service.cpp`
  - Validate files, switch modes, gate snapshot/recording in test mode, and hold `finished` state after EOF.
- `rk_app/src/health_videod/ipc/video_gateway.cpp`
  - Route the new actions.
- `rk_app/src/health_videod/pipeline/video_pipeline_backend.h`
  - Add a small observer contract so backends can notify `VideoService` when a test file finishes.
- `rk_app/src/health_videod/pipeline/gstreamer_video_pipeline_backend.h`
  - Store observer pointer and split camera/file command builders.
- `rk_app/src/health_videod/pipeline/gstreamer_video_pipeline_backend.cpp`
  - Build MP4 preview pipelines and emit playback-finished notifications for test-file sessions.
- `rk_app/src/health_ui/pages/video_monitor_page.h`
  - Add test-mode labels, buttons, and a file-picker callback injection point.
- `rk_app/src/health_ui/pages/video_monitor_page.cpp`
  - Wire file selection, request backend switches, and render mode/file state.
- `rk_app/src/health_ui/widgets/video_preview_widget.h`
  - Add a dedicated source badge API separate from the fall-classification overlay.
- `rk_app/src/health_ui/widgets/video_preview_widget.cpp`
  - Render `TEST MODE` + filename badge without interfering with person-state labels.
- `rk_app/src/health_ui/app/ui_app.cpp`
  - Construct `VideoMonitorPage` with the default file-picker lambda.

### Test files to modify

- `rk_app/src/tests/protocol_tests/video_protocol_test.cpp`
- `rk_app/src/tests/video_daemon_tests/video_service_test.cpp`
- `rk_app/src/tests/ipc_tests/video_gateway_test.cpp`
- `rk_app/src/tests/ui_tests/video_monitor_page_test.cpp`
- `rk_app/src/tests/ui_tests/video_preview_widget_test.cpp`

### Notes for decomposition

- Do **not** modify `health-falld` for this feature.
- Keep all source-mode knowledge inside shared video models/protocol, `health-videod`, and `health-ui`.
- Reuse `VideoChannelStatus` as the single source of truth instead of inventing a second channel or UI-only playback path.

### Build / test workspace

- Host build directory: `/tmp/rk_health_station-test-video-input-mode-build`
- Base smoke commands used throughout this plan:
  - `cmake --build /tmp/rk_health_station-test-video-input-mode-build -j4`
  - `ctest --test-dir /tmp/rk_health_station-test-video-input-mode-build --output-on-failure`

---

### Task 1: Extend shared status and UI IPC surface for test mode

**Files:**
- Modify: `rk_app/src/shared/models/video_models.h`
- Modify: `rk_app/src/shared/protocol/video_ipc.cpp`
- Modify: `rk_app/src/health_ui/ipc_client/video_ipc_client.h`
- Modify: `rk_app/src/health_ui/ipc_client/video_ipc_client.cpp`
- Test: `rk_app/src/tests/protocol_tests/video_protocol_test.cpp`

- [ ] **Step 1: Write the failing protocol test for test-mode fields and commands**

```cpp
void VideoProtocolTest::roundTripsTestInputStatusPayload() {
    VideoChannelStatus status;
    status.cameraId = QStringLiteral("front_cam");
    status.cameraState = VideoCameraState::Previewing;
    status.previewUrl = QStringLiteral("tcp://127.0.0.1:5602?transport=tcp_mjpeg&boundary=rkpreview");
    status.inputMode = QStringLiteral("test_file");
    status.testFilePath = QStringLiteral("/tmp/fall-demo.mp4");
    status.testPlaybackState = QStringLiteral("finished");

    const QJsonObject json = videoChannelStatusToJson(status);
    VideoChannelStatus decoded;
    QVERIFY(videoChannelStatusFromJson(json, &decoded));
    QCOMPARE(decoded.inputMode, QStringLiteral("test_file"));
    QCOMPARE(decoded.testFilePath, QStringLiteral("/tmp/fall-demo.mp4"));
    QCOMPARE(decoded.testPlaybackState, QStringLiteral("finished"));
}

void VideoProtocolTest::roundTripsStartTestInputCommandPayload() {
    VideoCommand command;
    command.action = QStringLiteral("start_test_input");
    command.requestId = QStringLiteral("video-2");
    command.cameraId = QStringLiteral("front_cam");
    command.payload.insert(QStringLiteral("file_path"), QStringLiteral("/tmp/fall-demo.mp4"));

    const QJsonObject json = videoCommandToJson(command);
    VideoCommand decoded;
    QVERIFY(videoCommandFromJson(json, &decoded));
    QCOMPARE(decoded.action, QStringLiteral("start_test_input"));
    QCOMPARE(decoded.payload.value(QStringLiteral("file_path")).toString(),
        QStringLiteral("/tmp/fall-demo.mp4"));
}
```

- [ ] **Step 2: Run the protocol test to verify it fails**

Run:

```bash
cmake --build /tmp/rk_health_station-test-video-input-mode-build --target video_protocol_test -j4
ctest --test-dir /tmp/rk_health_station-test-video-input-mode-build -R video_protocol_test --output-on-failure
```

Expected: FAIL because `VideoChannelStatus` does not yet have `inputMode`, `testFilePath`, or `testPlaybackState`.

- [ ] **Step 3: Add backend-owned test-mode fields to `VideoChannelStatus`**

```cpp
struct VideoChannelStatus {
    QString cameraId;
    QString displayName;
    QString devicePath;
    VideoCameraState cameraState = VideoCameraState::Unavailable;
    QString previewUrl;
    QString storageDir;
    QString lastSnapshotPath;
    QString currentRecordPath;
    QString lastError;
    bool recording = false;
    QString inputMode = QStringLiteral("camera");
    QString testFilePath;
    QString testPlaybackState = QStringLiteral("idle");
    VideoProfile previewProfile;
    VideoProfile snapshotProfile;
    VideoProfile recordProfile;
};
```

- [ ] **Step 4: Serialize and parse the new status fields**
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

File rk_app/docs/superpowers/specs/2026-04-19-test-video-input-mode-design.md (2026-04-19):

# Test Video Input Mode Design

**Date:** 2026-04-19
**Branch:** `feature/test-video-input-mode`
**Base:** `feature/bytetrack-fall-detection`

## Goal

Add a user-facing "test fall detection" mode that temporarily replaces the live camera input with a user-selected local MP4 file, while keeping the existing RK3588 fall-detection pipeline intact. In test mode, the preview area must show the test video, fall detection must run against the same frames, and the UI must clearly indicate that the system is no longer showing the real camera.
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

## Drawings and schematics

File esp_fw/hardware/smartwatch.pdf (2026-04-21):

1 MP

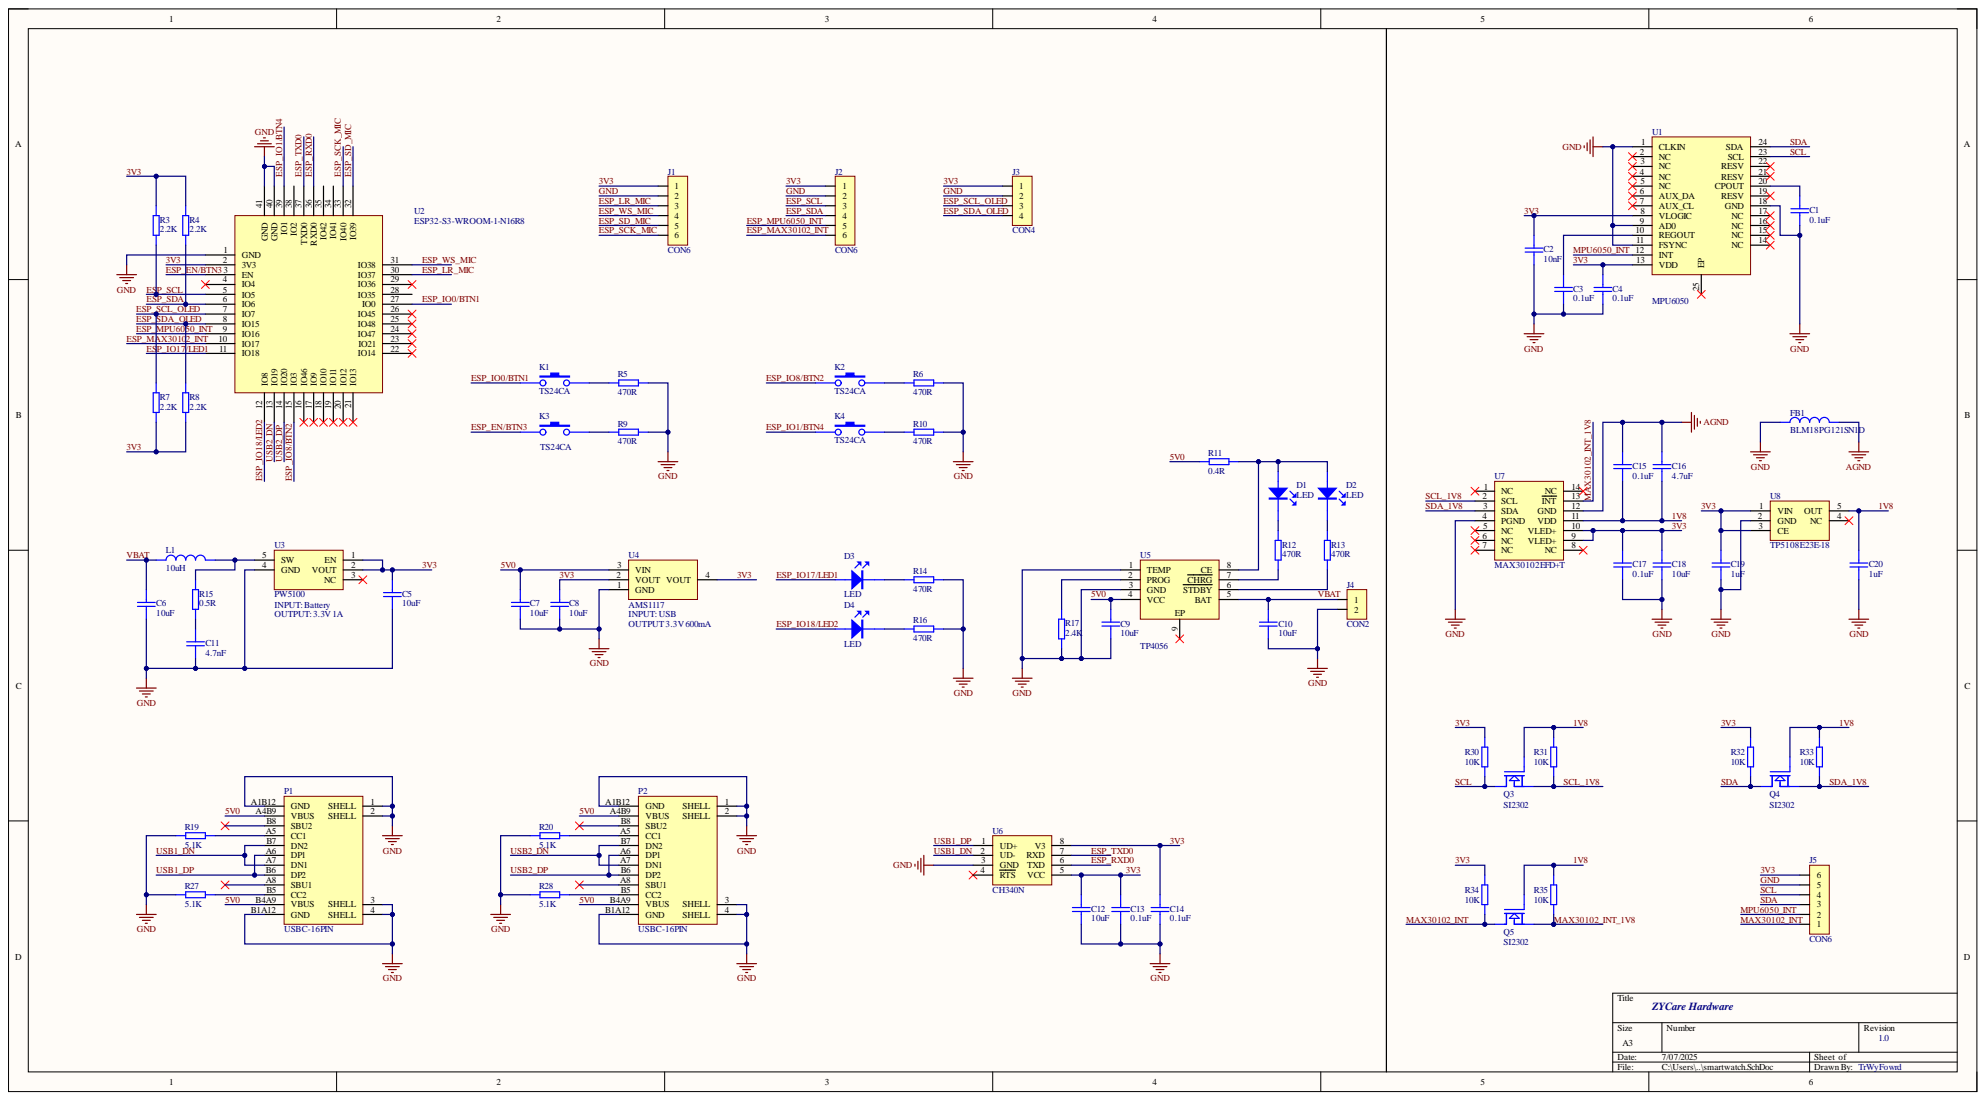
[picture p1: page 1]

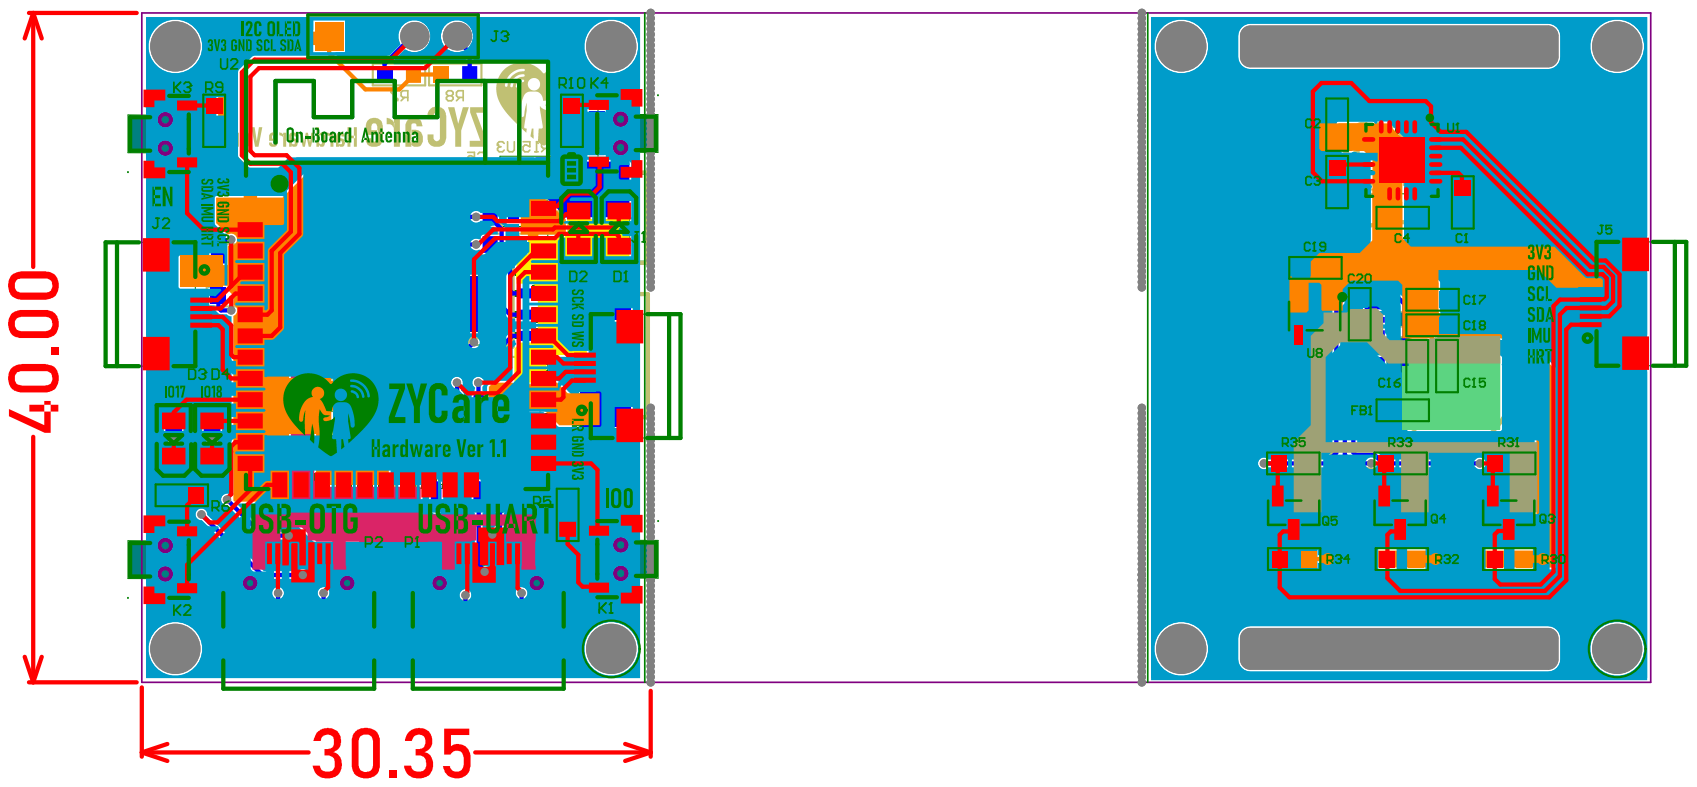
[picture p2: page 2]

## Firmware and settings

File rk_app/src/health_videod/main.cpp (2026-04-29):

#include "app/video_daemon_app.h"
#include "runtime_config/app_runtime_config_loader.h"

#include <QCoreApplication>
#include <QDebug>
#include <QSocketNotifier>

#include <csignal>

#include <sys/socket.h>
#include <unistd.h>

namespace {

int gSignalPipe[2] = {-1, -1};

void handleTerminationSignal(int signalNumber) {
    const char signalByte = static_cast<char>(signalNumber);
    if (gSignalPipe[1] >= 0) {
        const ssize_t ignored = ::write(gSignalPipe[1], &signalByte, sizeof(signalByte));
        (void)ignored;
    }
}

bool installSignalHandlers() {
    if (::socketpair(AF_UNIX, SOCK_STREAM, 0, gSignalPipe) != 0) {
        return false;
    }

    struct sigaction action;
    action.sa_handler = handleTerminationSignal;
    sigemptyset(&action.sa_mask);
    action.sa_flags = 0;

    return ::sigaction(SIGINT, &action, nullptr) == 0
        && ::sigaction(SIGTERM, &action, nullptr) == 0;
}

void closeSignalPipe() {
    for (int &fd : gSignalPipe) {
        if (fd >= 0) {
            ::close(fd);
            fd = -1;
        }
    }
}

} // namespace

int main(int argc, char *argv[]) {
    QCoreApplication app(argc, argv);
    qInfo() << "health-videod lifecycle: process start" << app.arguments();

    const LoadedAppRuntimeConfig loaded = loadAppRuntimeConfig(QString());
    if (!loaded.ok) {
        for (const QString &error : loaded.errors) {
            qCritical().noquote() << "runtime_config error:" << error;
        }
        return 1;
    }

    if (!installSignalHandlers()) {
        qCritical() << "health-videod lifecycle: failed to install signal handlers";
        return 1;
    }

    QSocketNotifier signalNotifier(gSignalPipe[0], QSocketNotifier::Read);
    QObject::connect(&signalNotifier, &QSocketNotifier::activated, &app, [&app, &signalNotifier]() {
        signalNotifier.setEnabled(false);
        char signalByte = 0;
        ::read(gSignalPipe[0], &signalByte, sizeof(signalByte));
        qInfo() << "health-videod lifecycle: graceful shutdown requested" << int(signalByte);
        app.quit();
        signalNotifier.setEnabled(true);
    });

    VideoDaemonApp daemon(loaded.config);
    const bool started = daemon.start();
    qInfo() << "health-videod lifecycle: daemon start result" << started;
    if (!started) {
        closeSignalPipe();
        return 1;
    }

    const int exitCode = app.exec();
    closeSignalPipe();
    return exitCode;
}

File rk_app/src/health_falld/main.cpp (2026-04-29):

#include "app/fall_daemon_app.h"
#include "runtime_config/app_runtime_config_loader.h"

#include <QCoreApplication>

int main(int argc, char *argv[]) {
    QCoreApplication app(argc, argv);

    const LoadedAppRuntimeConfig loaded = loadAppRuntimeConfig(QString());
    if (!loaded.ok) {
        for (const QString &error : loaded.errors) {
            qCritical().noquote() << "runtime_config error:" << error;
        }
        return 1;
    }

    FallDaemonApp daemon(loadFallRuntimeConfig(loaded.config));
    if (!daemon.start()) {
        return 1;
    }
    return app.exec();
}

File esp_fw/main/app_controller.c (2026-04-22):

#include "app_controller.h"

#include <math.h>
#include <stdlib.h>
#include <string.h>

#include "app_events.h"
#include "auth_client.h"
#include "board_config.h"
#include "device_config.h"
#include "driver/i2c.h"
#include "esp_log.h"
#include "esp_timer.h"
#include "freertos/FreeRTOS.h"
#include "freertos/event_groups.h"
#include "freertos/semphr.h"
#include "freertos/task.h"
#include "fall_classifier.h"
#include "heart_rate_algo.h"
#include "imu_event_state.h"
#include "imu_window_buffer.h"
#include "led_status.h"
#include "max30102.h"
#include "mpu6050.h"
#include "nvs_flash.h"
#include "provisioning_portal.h"
#include "signal_filter.h"
#include "system_diag.h"
#include "telemetry_uploader.h"
#include "wifi_manager.h"

#define MOTION_HISTORY_CAPACITY 64
#define SENSOR_INIT_RETRY_MS 2000
#define LINK_RETRY_MS 5000
#define PPG_MIN_ANALYSIS_SAMPLES 64

static const char *TAG = "APP_CTRL";
static const char *APP_FIRMWARE_VERSION = "0.1.0-dev";
static bool s_sensor_bus_ready = false;

typedef struct {
    EventGroupHandle_t events;
    SemaphoreHandle_t mutex;
    rk_device_config_t config;
    telemetry_vitals_t latest_vitals;
    signal_quality_t latest_quality;
    bool vitals_valid;
} app_runtime_t;

typedef struct {
    uint32_t ir_samples[SIGNAL_FILTER_MAX_SAMPLES];
    uint32_t red_samples[SIGNAL_FILTER_MAX_SAMPLES];
    float accel_norm_samples[MOTION_HISTORY_CAPACITY];
    float imu_window[256][6];
    signal_filter_window_t filter_window;
} sensor_task_buffers_t;

static app_runtime_t s_runtime;

static int64_t monotonic_ms(void)
{
    return esp_timer_get_time() / 1000;
}

static esp_err_t sensor_bus_init(void)
{
    const board_config_t *board = board_config_get();
    i2c_config_t i2c_conf = {
        .mode = I2C_MODE_MASTER,
        .sda_io_num = board->i2c_sda_pin,
        .scl_io_num = board->i2c_scl_pin,
        .sda_pullup_en = GPIO_PULLUP_ENABLE,
        .scl_pullup_en = GPIO_PULLUP_ENABLE,
        .master.clk_speed = 400000,
    };
    esp_err_t ret;

    if (s_sensor_bus_ready) {
        return ESP_OK;
    }

    ret = i2c_param_config(board->i2c_port, &i2c_conf);

    if (ret != ESP_OK) {
        return ret;
    }

    ret = i2c_driver_install(board->i2c_port, I2C_MODE_MASTER, 0, 0, 0);
    if (ret != ESP_OK) {
        return ret;
    }

    s_sensor_bus_ready = true;
    ESP_LOGI(TAG, "sensor bus ready on i2c=%d sda=%d scl=%d",
        (int)board->i2c_port,
        (int)board->i2c_sda_pin,
        (int)board->i2c_scl_pin);
    return ESP_OK;
}

static esp_err_t init_nvs_flash(void)
{
    esp_err_t ret = nvs_flash_init();

    if (ret == ESP_ERR_NVS_NO_FREE_PAGES || ret == ESP_ERR_NVS_NEW_VERSION_FOUND) {
        ESP_ERROR_CHECK(nvs_flash_erase());
        ret = nvs_flash_init();
    }

    return ret;
}

static void append_float(float *buffer, size_t capacity, size_t *count, float value)
{
    if (*count < capacity) {
        buffer[*count] = value;
        ++(*count);
        return;
    }

    memmove(buffer, buffer + 1, (capacity - 1) * sizeof(*buffer));
    buffer[capacity - 1] = value;
}

static void publish_vitals(const telemetry_vitals_t *vitals, const signal_quality_t *quality)
{
    xSemaphoreTake(s_runtime.mutex, portMAX_DELAY);
    s_runtime.latest_vitals = *vitals;
    s_runtime.latest_quality = *quality;
    s_runtime.vitals_valid = true;
    xSemaphoreGive(s_runtime.mutex);

    xEventGroupSetBits(s_runtime.events, APP_EVENT_VITALS_READY);
}

static bool snapshot_vitals(telemetry_vitals_t *vitals, signal_quality_t *quality)
{
    bool valid;

    xSemaphoreTake(s_runtime.mutex, portMAX_DELAY);
    valid = s_runtime.vitals_valid;
    if (valid) {
        *vitals = s_runtime.latest_vitals;
        *quality = s_runtime.latest_quality;
    }
    xSemaphoreGive(s_runtime.mutex);
    return valid;
}

static void sensor_task(void *arg)
{
    const board_config_t *board = board_config_get();
    const uint32_t ppg_period_ms = board->max30102_period_ms < 10 ? 10 : board->max30102_period_ms;
    sensor_task_buffers_t *buffers = calloc(1, sizeof(*buffers));
    max30102_config_t max_cfg = {
        .i2c_port = board->i2c_port,
        .bus_speed_hz = 400000,
        .red_led_amplitude = 0x24,
        .ir_led_amplitude = 0x24,
    };
    mpu6050_config_t mpu_cfg = {
        .i2c_port = board->i2c_port,
        .bus_speed_hz = 400000,
        .accel_range = MPU6050_ACCEL_RANGE_4G,
        .gyro_range = MPU6050_GYRO_RANGE_500,
        .bandwidth = MPU6050_BAND_21_HZ,
    };
    max30102_handle_t max_handle = NULL;
    mpu6050_handle_t mpu_handle = NULL;
    size_t ppg_count = 0;
    size_t motion_count = 0;
    int64_t next_telemetry_ms = monotonic_ms() + (int64_t)board->telemetry_period_ms;
    int64_t next_mpu_ms = monotonic_ms();
    imu_window_buffer_t imu_buffer = {0};
    imu_event_state_t imu_state = {0};
    telemetry_imu_fall_t latest_imu_fall = {0};
    bool fall_classifier_ready = false;

    (void)arg;

    if (buffers == NULL) {
        xEventGroupSetBits(s_runtime.events, APP_EVENT_SENSOR_FAULT);
        ESP_LOGE(TAG, "sensor task buffer allocation failed");
        vTaskDelete(NULL);
        return;
    }

    imu_window_buffer_init(&imu_buffer, 256, 32);
    imu_event_state_init(&imu_state, 2);

    while (true) {
        max30102_sample_t ppg_sample = {0};
        signal_quality_t quality = {0};
        heart_rate_result_t hr_result = {0};
        telemetry_vitals_t vitals = {0};
        mpu6050_sample_t motion_sample = {0};
        int64_t now_ms = monotonic_ms();

        if ((max_handle == NULL || mpu_handle == NULL) && sensor_bus_init() != ESP_OK) {
            xEventGroupSetBits(s_runtime.events, APP_EVENT_SENSOR_FAULT);
            ESP_LOGW(TAG, "sensor bus init failed, retry in %d ms", SENSOR_INIT_RETRY_MS);
            vTaskDelay(pdMS_TO_TICKS(SENSOR_INIT_RETRY_MS));
            continue;
        }

        if (max_handle == NULL) {
            esp_err_t ret = max30102_init(&max_cfg, &max_handle);
            if (ret == ESP_OK) {
                ret = max30102_configure(max_handle);
            }
            if (ret != ESP_OK) {
                if (max_handle != NULL) {
                    max30102_deinit(max_handle);
                    max_handle = NULL;
                }
                xEventGroupSetBits(s_runtime.events, APP_EVENT_SENSOR_FAULT);
                ESP_LOGW(TAG,
                    "max30102 init/configure failed: %s, retry in %d ms",
                    esp_err_to_name(ret),
                    SENSOR_INIT_RETRY_MS);
                vTaskDelay(pdMS_TO_TICKS(SENSOR_INIT_RETRY_MS));
                continue;
            }
            ESP_LOGI(TAG, "max30102 streaming at %lu ms/sample", (unsigned long)ppg_period_ms);
        }
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

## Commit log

2026-04-17 chore: track missing ui headers
2026-04-17 chore: track missing ui ipc header
2026-04-17 refactor: isolate per-track fall action context
2026-04-18 fix: keep new ByteTrack tracks tracked on first frame
2026-04-19 Fix board-side LSTM test video inference
2026-04-20 Add optional fall tracking trace output
2026-04-20 Add track icon overlay design spec
2026-04-20 Add track icon overlay implementation plan
2026-04-20 Publish stable track icon overlay metadata
2026-04-20 Show track icon ids in monitor overlay rows
2026-04-20 Render track icon overlay in video preview
2026-04-20 Emit single-track overlay batches for UI badges
2026-04-21 feat: bootstrap standalone esp firmware project
    [partitions.csv]
2026-04-21 feat: add sensor drivers and vital sign algorithms
2026-04-21 feat: orchestrate runtime tasks and led state signaling
2026-04-21 docs: add esp32s3 imu fall model design spec
2026-04-21 feat: add esp32s3 imu fall telemetry pipeline
2026-04-21 chore: add esp hardware assets
    [smartwatch.PcbDoc, smartwatch.PcbLib, smartwatch.PrjPcb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]
2026-04-22 feat: harden esp sensor and provisioning runtime
2026-04-22 fix: run aligned esp-dl imu model with psram
2026-04-23 refactor: add analysis frame descriptor protocol
2026-04-23 feat: read analysis frames from shared memory
2026-04-23 fix: preserve shm analysis frame bursts
2026-04-25 feat: use RK MPP JPEG encoder for video preview
2026-04-27 chore: add dmabuf capability probes
2026-04-29 fix: harden runtime config startup paths
    [main.cpp]
2026-05-01 refactor: extract gst command and dma helpers
2026-05-01 refactor: extract analysis frame publisher
